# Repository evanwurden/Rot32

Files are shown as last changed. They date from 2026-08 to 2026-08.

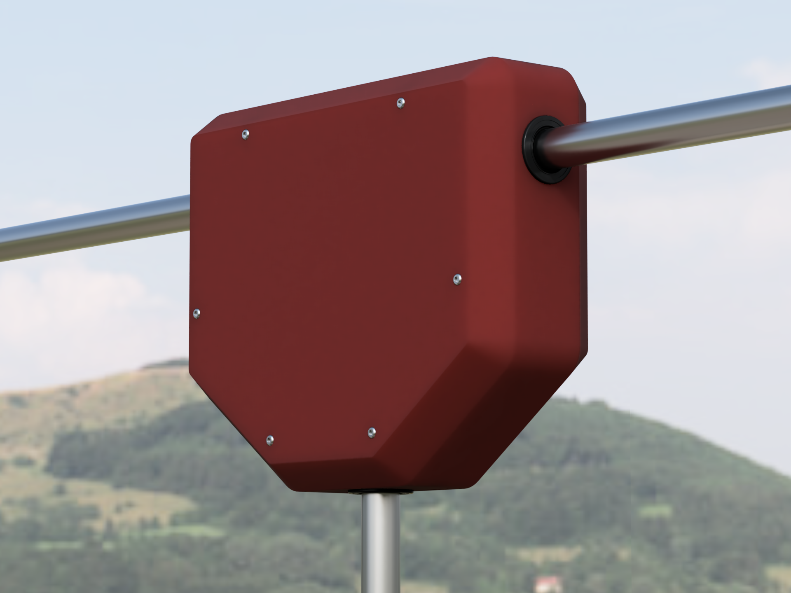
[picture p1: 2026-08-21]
3D Models/Images/AssembledView.png

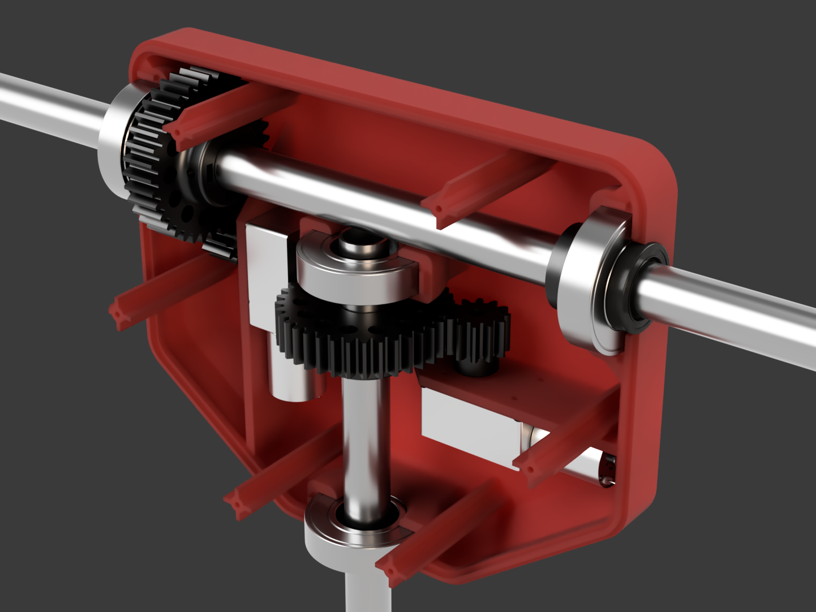
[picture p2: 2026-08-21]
3D Models/Images/TopRightView.png

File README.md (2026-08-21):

# Rot32

Rot32 is an extremely low-cost (<150USD) ESP32-based antenna rotator which is suitable for amateur radio operators or hobbyists. It utilizes commonly available hardware and is easy to assemble, wire, and program.

# Features
- 3D printable enclosure and gearing. Enclosure fits within 256x256mm bed 
- LSM303 Accelerometer/Magnetometer automatically determines the current heading and elevation
- Worm gear motor drive locks position without power applied
- Wide antenna mast can steer multiple antennas at once while staying
- Rotctld protocol emulation over Wi-Fi allows all hamlib compatible applications to interface with the rotator
- Web interface for manual steering and changing motion and calibration parameters on the fly.

<br>

# Build

## Bill Of Materials
- 1kg Spool 3D Printing Filament (Preferably PETG, ABS/ASA)
- 4x R16-2RS Ball Bearings (2in OD, 1in ID, 1/2in Thickness)
- About 5ft 0.75in aluminum tubing
- 2x JGY-370 12V 6rpm DC Worm Gear Motor
- 6x M3 Plastite Screws
- M3/M4 Nut/Screw Assortment
- ESP32-S3 Dev Board
- L298N H-Bridge Motor Driver

## Wiring

Defaults from `config.py` for ESP32-S3

| Signal | Pin |
|---|---|
| I2C SDA | GPIO8 |
| I2C SCL | GPIO9 |
| AZ+ / AZ- (PWM) | GPIO4 / GPIO5 |
| EL+ / EL- (PWM) | GPIO6 / GPIO7 |

## Firmware Install

1. Flash MicroPython from
   [micropython.org/download](https://micropython.org/download/) for your
   module.
2. Edit `config.py`: set `WIFI_SSID`, `WIFI_PASSWORD`, and the pin numbers.
3. Copy the project files to the device, e.g. `mpremote cp *.py *.html :`.
4. Reset the board. The IP address is recorded in the log, readable at
   `http://<device-ip>/api/log` or over serial with `SERIAL_LOGGING_ENABLED`.

<br>

# Usage 
## Web UI

Browse to `http://<device-ip>/` for a simple control interface:

- **Position**: live azimuth/elevation readout, plus the current target
  while a move is in progress.
- **Manual control**: press-and-hold direction buttons plus a speed slider.
- **Go To Position**: numeric azimuth/elevation entry, plus Park and Reset.
- **Motion Tuning**: arrival window, arrival speed, slow-down distance, and
  acceleration.
- **Calibration**: declination, offsets, invert flags, axis selection,
  smoothing, and a magnetometer calibration wizard.

## First-time setup

1. Pick the **azimuth forward axis**: rotate the antenna while level and try
   each of X/Y/Z until the Azimuth readout tracks correctly. Then tilt to a
   nonzero elevation and rotate again to confirm it is still accurate.
2. Pick the **elevation axis pair**: choose whichever of XY/XZ/YZ changes as
   you tilt the sensor.
3. Run the **magnetometer calibration wizard**: click Start, sweep the sensor
   through a full 360 degrees for 30 to 60 seconds, then click Finish.
4. Set **magnetic declination** for your location, then trim the azimuth and
   elevation offsets.
5. Raise **Smoothing** if the readout is jittery. Keep it at 0% while tuning
   axes and offsets so the display reacts immediately.

If azimuth is accurate at one heading but drifts at others, that is magnetic
distortion near the sensor. Use the wizard, not the offset field, which
shifts every heading by the same amount.

## rotctld

TCP server on port `4533`, accepting short and long command forms.

| Command | Long form |
|---|---|
| `P Az El` | `\set_pos` |
| `p` | `\get_pos` |
| `M Dir Speed` | `\move` |
| `S` | `\stop` |
| `K` | `\park` |
| `R 1` | `\reset` |
| `_` | `\get_info` |
| `1` | `\dump_caps` |
| `dump_state` | |

Direction values for `M`: `2` up, `4` down, `8` left, `16` right. Locator
commands are recognised but return unsupported.

```sh
printf 'p\n'         | nc 192.168.1.50 4533
printf 'P 180 30\n'  | nc 192.168.1.50 4533
printf 'M 16 60\n'   | nc 192.168.1.50 4533
printf 'S\n'         | nc 192.168.1.50 4533
```

The extended response protocol is supported by prefixing a command with `+`:

```sh
printf '+\\get_pos\n' | nc 192.168.1.50 4533
```

# Future Improvements
- Enclosure design should be tested to failure and revised accordingly. There is room for improvement in the screw standoff design which mates the two halves.
- Better waterproofing could be achieved through gasketing material around the edges and using shaft seals or some other 3D printed rubber to prevent water ingress at the bearings.
- Spur gear design can be revised to reduce backlash. A belt-drive was tested but tensioning became complicated and required more space.
- Gear-to-pipe connections should use a circumferential clamping force rather than a set screw. Aluminum is soft and a screw pressing directly into the pipe works itself loose over time.
- Encoders can be implemented for better precision. JGY worm gear motors are available with built-in encoders.
- LSM303 motion algorithm can be improved. Magnetometer calibration is quite good for static precision but polling rate and filtering could use some work.

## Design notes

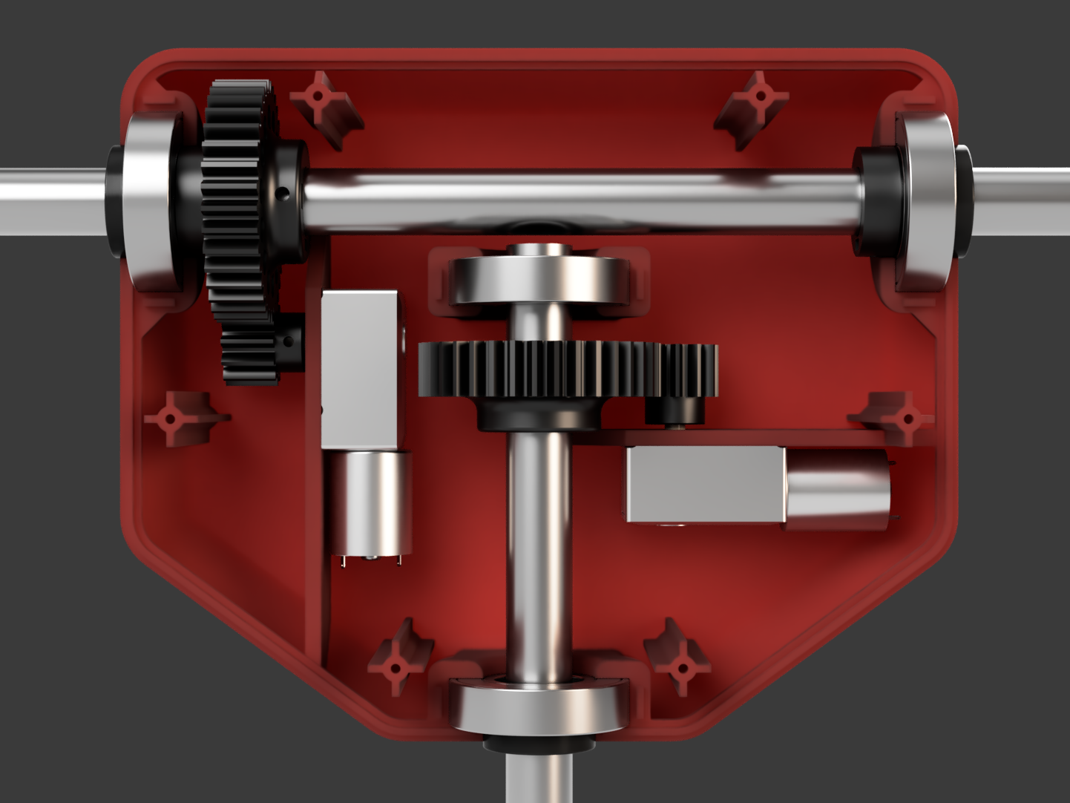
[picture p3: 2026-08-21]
3D Models/Images/FrontView.png

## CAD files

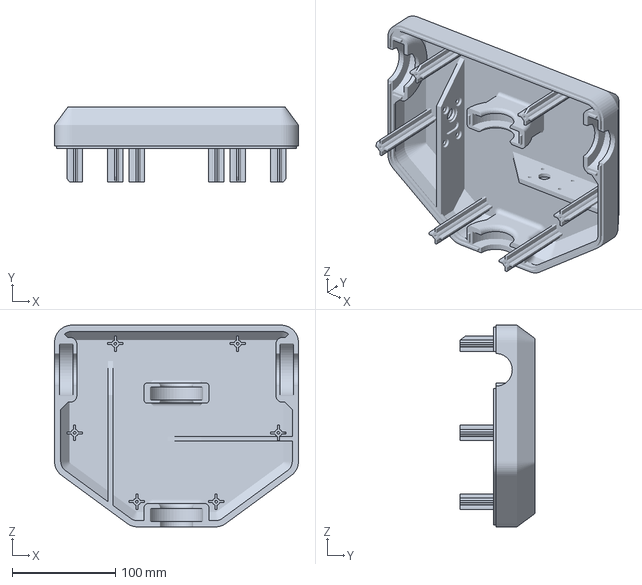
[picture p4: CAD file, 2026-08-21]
3D Models/Rotator Body Main.3mf
236.7 x 72.9 x 195.8 mm

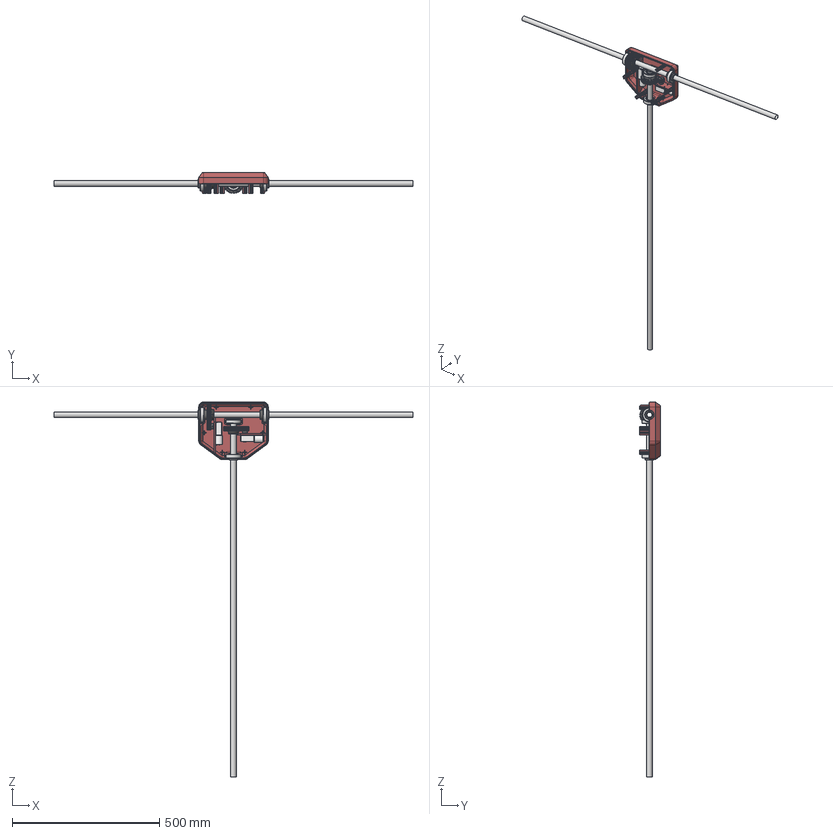
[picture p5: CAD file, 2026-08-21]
3D Models/Assembly.step
1219.2 x 72.9 x 1275.0 mm
Pipe x 2
4648K19_440C Stainless Steel Ball Bearing for Food and Beverage x 4
COVER x 2
GEAR BODY x 2
SHAFT x 2
DC MOTOR BODY x 2
DC MOTOR SHAFT x 2
M2 X 6 SS FLAT HEAD SCREW_default x 8
Spur Gear 12 teeth x 2
Spur Gear 36 teeth x 2
1199N64_Spring-Loaded Rotary Shaft Seal with Wiper Lip x 3

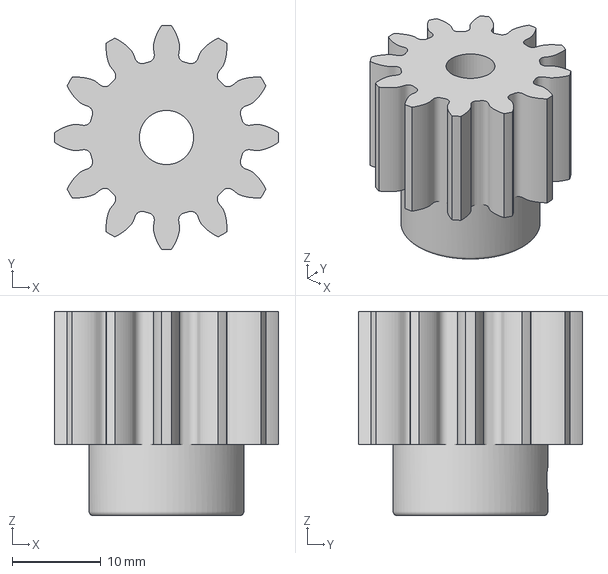
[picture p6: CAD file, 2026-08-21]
3D Models/12 Tooth Gear.3mf
25.2 x 25.2 x 23.0 mm

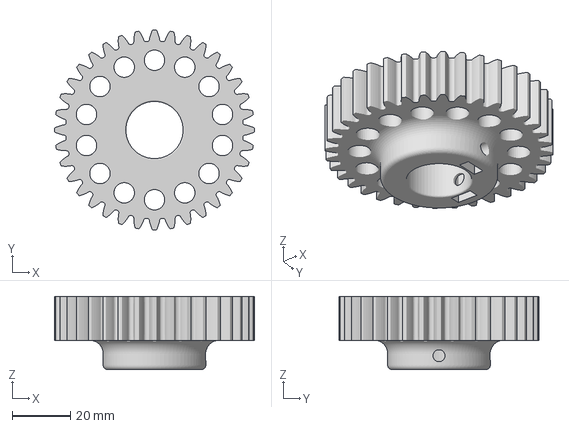
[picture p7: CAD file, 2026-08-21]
3D Models/36 Tooth Gear.3mf
68.4 x 68.4 x 25.0 mm

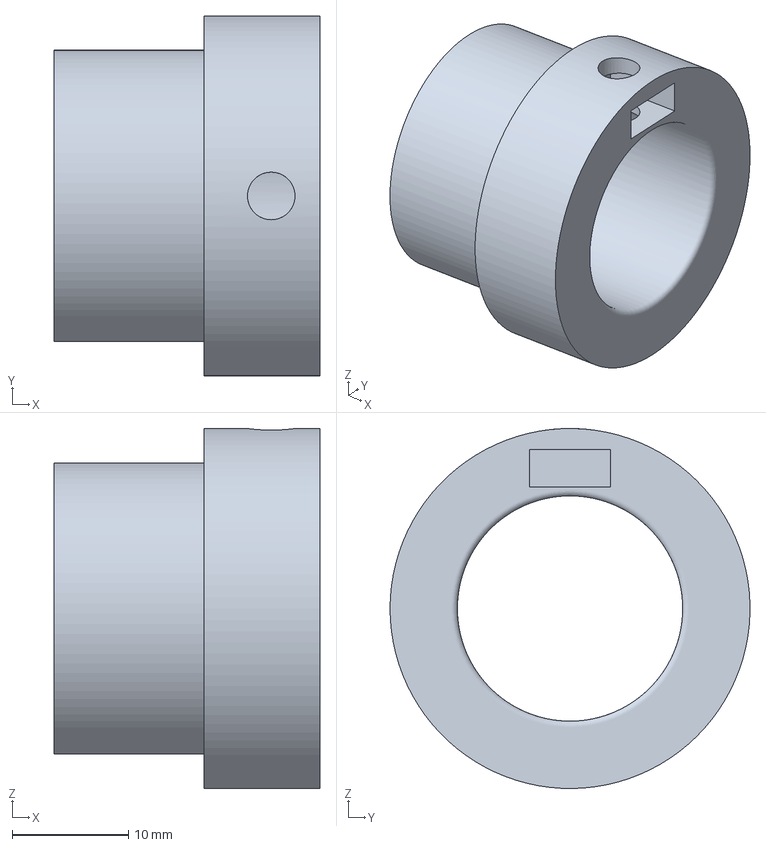
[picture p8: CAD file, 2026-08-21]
3D Models/Aluminum Tube Bearing Bushing.3mf
22.9 x 31.0 x 31.0 mm

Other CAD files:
3D Models/Rotator Body Cover.3mf

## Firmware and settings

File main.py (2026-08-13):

import time
from machine import I2C, WDT, Pin

import config
import store
from lsm303 import LSM303
from rotator_controller import RotatorController
from rotctld_server import RotctldServer
from web_server import WebServer
from wifi_manager import attempt_reconnect, connect_wifi, get_wlan, is_connected

SENSOR_RETRY_MS = 5000

# Rate limits for messages that would otherwise repeat every loop tick and
# fill up the log buffer.
ACCEPT_ERROR_LOG_MS = 5000
LOG_REPEAT_MS = 30000

# How often to retry a listening socket that is not up yet.
SERVER_REBIND_RETRY_MS = 10000

# Recent status/diagnostic messages, served at GET /api/log.
LOG_BUFFER_SIZE = 40
log_buffer = []

# Runtime copy of config.SERIAL_LOGGING_ENABLED. It turns off for good the
# first time a console write raises.
_serial_logging = config.SERIAL_LOGGING_ENABLED

_repeat_state = {}


def _default_tuning():
    """Returns config.py's motion-tuning defaults, the baseline a saved
    tuning.json overrides. Rebuilt on each call so a caller cannot mutate
    it."""
    return {
        "position_tolerance_deg": float(config.POSITION_TOLERANCE_DEG),
        "approach_speed_percent": float(config.APPROACH_SPEED_PERCENT),
        "speed_ramp_deg": float(config.SPEED_RAMP_DEG),
        "speed_accel_percent_per_sec": float(config.SPEED_ACCEL_PERCENT_PER_SEC),
    }


def _sensor_settings(saved):
    """Returns LSM303 settings from a saved calibration dict. Falls back to
    config.py for any field the dict does not have."""
    return {
        "mag_declination_deg": saved.get("mag_declination_deg", config.MAG_DECLINATION_DEG),
        "azimuth_offset_deg": saved.get("azimuth_offset_deg", config.AZIMUTH_OFFSET_DEG),
        "elevation_offset_deg": saved.get("elevation_offset_deg", config.ELEVATION_OFFSET_DEG),
        "invert_azimuth": saved.get("invert_azimuth", config.INVERT_AZIMUTH),
        "invert_elevation": saved.get("invert_elevation", config.INVERT_ELEVATION),
        "mag_offset_x": saved.get("mag_offset_x", 0.0),
        "mag_offset_y": saved.get("mag_offset_y", 0.0),
        "mag_offset_z": saved.get("mag_offset_z", 0.0),
        "mag_scale_x": saved.get("mag_scale_x", 1.0),
        "mag_scale_y": saved.get("mag_scale_y", 1.0),
        "mag_scale_z": saved.get("mag_scale_z", 1.0),
        "azimuth_forward_axis": saved.get("azimuth_forward_axis", config.AZIMUTH_FORWARD_AXIS),
        "elevation_axis_pair": saved.get("elevation_axis_pair", config.ELEVATION_AXIS_PAIR),
        "filter_strength": saved.get("filter_strength", config.FILTER_STRENGTH),
        "motion_threshold_deg": saved.get("motion_threshold_deg", config.MOTION_THRESHOLD_DEG),
        "accel_odr_hz": config.ACCEL_ODR_HZ,
        "mag_odr_hz": config.MAG_ODR_HZ,
    }


def _log(*args):
    """Appends a message to the ring buffer, and echoes it to the console if
    serial logging is on. A console write that raises turns off serial
    output for the rest of the run."""
    global _serial_logging

    msg = " ".join(str(a) for a in args)
    log_buffer.append(msg)
    if len(log_buffer) > LOG_BUFFER_SIZE:
        del log_buffer[0]
    if _serial_logging:
        try:
            print(msg)
        except Exception:
            _serial_logging = False


def _log_repeating(key, msg):
    """Logs msg, but skips an identical consecutive messages for
    LOG_REPEAT_MS."""
    now = time.ticks_ms()
    previous = _repeat_state.get(key)
    if (
        previous is not None
        and previous[0] == msg
        and time.ticks_diff(now, previous[1]) < LOG_REPEAT_MS
    ):
        return
    _repeat_state[key] = (msg, now)
    _log(msg)


class _UnavailableController:
    """Stand-in used when RotatorController fails to construct."""
    target_az = None
    target_el = None
    manual_direction = None
    manual_speed = 0
    min_elevation_deg = 0.0
    max_elevation_deg = 0.0
    last_error = None

    # Borrowed from the real controller, so /api/tuning can still show its
    # bounds.
    TUNING_LIMITS = RotatorController.TUNING_LIMITS

    def __init__(self, reason):
        self.last_error = "Motor controller unavailable: {}".format(reason)

    def get_position(self):
        return None, None

    def update(self):
        return False

    def stop(self):
        pass

    def reset(self):
        pass

    def move(self, direction, speed_percent):
        raise OSError(self.last_error)

    def set_target(self, azimuth_deg, elevation_deg):
        raise OSError(self.last_error)

    def park(self):
        raise OSError(self.last_error)

    def get_tuning(self):
        return _default_tuning()

    def set_tuning(self, **values):
        raise OSError(self.last_error)


def main():
    try:
        i2c = I2C(
            0,
            sda=Pin(config.I2C_SDA_PIN),
            scl=Pin(config.I2C_SCL_PIN),
            freq=config.I2C_FREQ_HZ,
        )
    except Exception as e:
        i2c = None
        _log("I2C bus init failed, sensor will stay unavailable:", repr(e))

    saved_cal = store.load(store.CALIBRATION_FILE)
    saved_tuning = store.load(store.TUNING_FILE)

    # Retries with an empty calibration if the saved file itself is broken
    try:
        sensor = LSM303(i2c=i2c, **_sensor_settings(saved_cal))
    except Exception as e:
        _log("Saved calibration.json invalid, falling back to config.py defaults:", repr(e))
        sensor = LSM303(i2c=i2c, **_sensor_settings({}))

    # If the sensor does not initialize, log it
    last_sensor_attempt_ms = time.ticks_ms()
    try:
        sensor.begin()
        _log("LSM303 sensor ready")
    except Exception as e:
        _log("LSM303 sensor init failed (retrying):", repr(e))

    try:
        controller = RotatorController(
            sensor=sensor,
            az_plus_pin=config.AZ_PLUS_PIN,
            az_minus_pin=config.AZ_MINUS_PIN,
            el_plus_pin=config.EL_PLUS_PIN,
            el_minus_pin=config.EL_MINUS_PIN,
            pwm_freq_hz=config.PWM_FREQUENCY_HZ,
            position_tolerance_deg=config.POSITION_TOLERANCE_DEG,
            control_update_ms=config.CONTROL_UPDATE_MS,
            min_elevation_deg=config.MIN_ELEVATION_DEG,
            max_elevation_deg=config.MAX_ELEVATION_DEG,
            park_azimuth_deg=config.PARK_AZIMUTH_DEG,
            park_elevation_deg=config.PARK_ELEVATION_DEG,
            approach_speed_percent=config.APPROACH_SPEED_PERCENT,
            speed_ramp_deg=config.SPEED_RAMP_DEG,
            speed_accel_percent_per_sec=config.SPEED_ACCEL_PERCENT_PER_SEC,
        )
    except Exception as e:
        _log("Motor controller init failed.", repr(e))
        controller = _UnavailableController(repr(e))

    if saved_tuning and not isinstance(controller, _UnavailableController):
        try:
            controller.set_tuning(**saved_tuning)
            _log("motion tuning loaded from tuning.json")
        except Exception as e:
            _log("saved tuning.json invalid, using config.py defaults:", repr(e))

    try:
        wlan = get_wlan(
            power_save_disabled=config.WIFI_POWER_SAVE_DISABLED,
            txpower_dbm=config.WIFI_TX_POWER_DBM,
        )
    except Exception as e:
        wlan = None
        _log("Wi-Fi hardware init failed:", repr(e))
    try:
        ip = connect_wifi(
            config.WIFI_SSID,
            config.WIFI_PASSWORD,
            timeout_s=config.WIFI_CONNECT_TIMEOUT_S,
            power_save_disabled=config.WIFI_POWER_SAVE_DISABLED,
            txpower_dbm=config.WIFI_TX_POWER_DBM,
        )
        _log("Wi-Fi connected, IP:", ip)
    except Exception as e:
        _log("Wi-Fi connect failed at boot (will keep retrying):", repr(e))

    server = RotctldServer(
        controller=controller,
        host=config.ROTCTLD_HOST,
        port=config.ROTCTLD_PORT,
        client_idle_ms=config.ROTCTLD_CLIENT_IDLE_MS,
        max_clients=config.MAX_CLIENTS_PER_SERVER,
    )
    try:
        server.start()
        _log("rotctld server listening on {}:{}".format(config.ROTCTLD_HOST, config.ROTCTLD_PORT))
    except Exception as e:
        _log("rotctld server failed to start:", repr(e))

    web_server = WebServer(
        controller=controller,
        sensor=sensor,
        store=store,
        default_tuning=_default_tuning(),
        wlan=wlan,
        log_buffer=log_buffer,
        host=config.WEB_HOST,
        port=config.WEB_PORT,
        client_idle_ms=config.WEB_CLIENT_IDLE_MS,
        max_clients=config.MAX_CLIENTS_PER_SERVER,
    )
    try:
        web_server.start()
        _log("web UI listening on {}:{}".format(config.WEB_HOST, config.WEB_PORT))
    except Exception as e:
        _log("web server failed to start:", repr(e))

    last_wifi_attempt_ms = time.ticks_ms()
    wifi_was_connected = is_connected(wlan)
    wifi_failures = 0
    last_accept_log_ms = time.ticks_ms()
    last_bind_retry_ms = time.ticks_ms()
    bind_failure_logged = set()

    def _rebind(srv, name):
        """Reopens a server's listening socket after Wi-Fi comes back."""
        try:
            srv.restart()
            _log(name, "rebound after Wi-Fi reconnect")
        except Exception as e:
            _log(name, "failed to rebind after Wi-Fi reconnect:", repr(e))

    wdt = None
    if config.WDT_ENABLED:
        try:
            wdt = WDT(timeout=config.WDT_TIMEOUT_MS)
            _log("watchdog armed ({} ms)".format(config.WDT_TIMEOUT_MS))
        except Exception as e:
            _log("watchdog unavailable (continuing without it):", repr(e))

    try:
        while True:
            if wdt is not None:
                wdt.feed()

            now = time.ticks_ms()

            if wlan is not None and is_connected(wlan):
                if not wifi_was_connected:
                    _log("Wi-Fi connected, IP:", wlan.ifconfig()[0])
                    # A socket bound before the interface went down does not
                    # reliably keep accepting once the interface is rebuilt.
                    _rebind(server, "rotctld server")
                    _rebind(web_server, "web server")
                wifi_was_connected = True
                wifi_failures = 0
            else:
                if wifi_was_connected:
                    _log("Wi-Fi disconnected")
                wifi_was_connected = False
                if wlan is not None and time.ticks_diff(now, last_wifi_attempt_ms) >= config.WIFI_RECONNECT_MS:
                    last_wifi_attempt_ms = now
                    wifi_failures = attempt_reconnect(
                        wlan,
                        config.WIFI_SSID,
                        config.WIFI_PASSWORD,
                        consecutive_failures=wifi_failures,
                        hard_reset_after=config.WIFI_HARD_RESET_AFTER_ATTEMPTS,
                        power_save_disabled=config.WIFI_POWER_SAVE_DISABLED,
                        txpower_dbm=config.WIFI_TX_POWER_DBM,
                    )
                    _log("Wi-Fi reconnect attempt", wifi_failures)

            if time.ticks_diff(now, last_accept_log_ms) >= ACCEPT_ERROR_LOG_MS:
                last_accept_log_ms = now
                for srv, name in ((server, "rotctld"), (web_server, "web")):
                    if srv.last_accept_error is not None:
                        _log(
                            name,
                            "accept failed (socket pool exhausted?):",
                            srv.last_accept_error,
                        )
                        srv.last_accept_error = None

            # Retries any listening socket that is not up
            if time.ticks_diff(now, last_bind_retry_ms) >= SERVER_REBIND_RETRY_MS:
                last_bind_retry_ms = now
                for key, srv, name in (
                    ("rotctld", server, "rotctld server"),
                    ("web", web_server, "web server"),
                ):
                    if srv.server is not None:
                        continue
                    try:
                        srv.start()
                        bind_failure_logged.discard(key)
                        _log(name, "listening again")
                    except Exception as e:
                        if key not in bind_failure_logged:
                            bind_failure_logged.add(key)
                            _log(name, "not listening, will keep retrying:", repr(e))

            if not sensor.ready:
                if time.ticks_diff(now, last_sensor_attempt_ms) >= SENSOR_RETRY_MS:
                    last_sensor_attempt_ms = now
                    try:
                        sensor.begin()
                        _log("LSM303 sensor ready")
                    except Exception as e:
                        _log_repeating(
                            "sensor", "LSM303 sensor init retry failed: " + repr(e)
                        )

            try:
                if controller.update():
                    controller.last_error = None
            except Exception as e:
                controller.last_error = "{}: {}".format(type(e).__name__, e)
                _log_repeating(
                    "control", "controller update error: " + controller.last_error
                )

            try:
                server.poll_once()
            except Exception as e:
                _log("server poll error:", repr(e))
            try:
                web_server.poll_once()
            except Exception as e:
                _log("web server poll error:", repr(e))

            # Keep this below CONTROL_UPDATE_MS
            time.sleep_ms(10)
    finally:
        controller.stop()
        server.close()
        web_server.close()


if __name__ == "__main__":
    main()

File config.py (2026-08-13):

"""Rot32 configuration"""

# Wi-Fi settings
WIFI_SSID = "YOUR_SSID_HERE"
WIFI_PASSWORD = "YOUR_PASS_HERE"

# WIFI_CONNECT_TIMEOUT_S: how long the boot connect waits before it gives
# up. This does not stop startup.
WIFI_CONNECT_TIMEOUT_S = 20
# WIFI_RECONNECT_MS: how often it retries the connection while offline
WIFI_RECONNECT_MS = 10_000

WIFI_HARD_RESET_AFTER_ATTEMPTS = 5
WIFI_POWER_SAVE_DISABLED = True

# Transmit power cap in dBm. None leaves it uncapped
WIFI_TX_POWER_DBM = None

# Hardware watchdog
WDT_ENABLED = True
WDT_TIMEOUT_MS = 30000

# Logs to the serial console. Keep this off without a USB connection
SERIAL_LOGGING_ENABLED = False

# rotctld server settings
ROTCTLD_HOST = "0.0.0.0"
ROTCTLD_PORT = 4533

# Web control/calibration UI settings
WEB_HOST = "0.0.0.0"
WEB_PORT = 80

# Closes an idle client after no traffic for this long
WEB_CLIENT_IDLE_MS = 15_000
ROTCTLD_CLIENT_IDLE_MS = 300_000

MAX_CLIENTS_PER_SERVER = 4

# I2C pins for the LSM303 sensor. GPIO8 and GPIO9 are safe on ESP32-S3
I2C_SDA_PIN = 8
I2C_SCL_PIN = 9
I2C_FREQ_HZ = 400_000

# LSM303 output data rates.
# ACCEL_ODR_HZ (1/10/25/50/100/200/400)
ACCEL_ODR_HZ = 100
# MAG_ODR_HZ (15/30/75/220)
# Keep this above 1000/CONTROL_UPDATE_MS. Otherwise the control loop reads
# stale values.
MAG_ODR_HZ = 75

# Motor driver. GPIO4 to GPIO7 are safe on ESP32-S3
AZ_PLUS_PIN = 4
AZ_MINUS_PIN = 5
EL_PLUS_PIN = 6
EL_MINUS_PIN = 7
PWM_FREQUENCY_HZ = 500

# Control loop period, roughly 50 Hz
CONTROL_UPDATE_MS = 20

POSITION_TOLERANCE_DEG = 1.5
MAX_ELEVATION_DEG = 90.0
MIN_ELEVATION_DEG = -10.0

# Speed ramping. APPROACH_SPEED_PERCENT is the speed the rotator arrives at,
# SPEED_RAMP_DEG is how far out the taper down to it begins, and
# SPEED_ACCEL_PERCENT_PER_SEC caps how fast commanded speed may change.
APPROACH_SPEED_PERCENT = 15.0
SPEED_RAMP_DEG = 15.0
SPEED_ACCEL_PERCENT_PER_SEC = 200.0

# Optional sensor/orientation calibration
MAG_DECLINATION_DEG = 0.0
AZIMUTH_OFFSET_DEG = 0.0
ELEVATION_OFFSET_DEG = 0.0
INVERT_AZIMUTH = False
INVERT_ELEVATION = False

# AZIMUTH_FORWARD_AXIS: axis that lies parallel to the antenna. 
AZIMUTH_FORWARD_AXIS = "X"

# ELEVATION_AXIS_PAIR: axis pair ("XY", "XZ" or "YZ") that
# elevation reads from. Pick the pair that changes as you tilt the sensor.
ELEVATION_AXIS_PAIR = "XZ"

# Exponential-moving-average smoothing on the azimuth and elevation output
FILTER_STRENGTH = 0.95

# Deviation above which smoothing turns off and a reading is treated as a
# real move, not wind or noise
MOTION_THRESHOLD_DEG = 3.0

# Park position
PARK_AZIMUTH_DEG = 0.0
PARK_ELEVATION_DEG = 0.0

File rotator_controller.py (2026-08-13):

import time
from machine import PWM, Pin


class RotatorController:
    """Closed-loop azimuth and elevation control using four PWM outputs that
    drive an H-bridge."""

    DIR_UP = 2
    DIR_DOWN = 4
    DIR_LEFT = 8
    DIR_RIGHT = 16

    # Largest gap, as a multiple of control_update_ms, that one cycle may
    # use for its acceleration step
    MAX_RAMP_INTERVAL_FACTOR = 4

    # Motion parameters editable via the web UI or /api/tuning.
    # Bounds apply on every write.
    TUNING_LIMITS = {
        "position_tolerance_deg": (0.1, 30.0),
        "approach_speed_percent": (1.0, 100.0),
        "speed_ramp_deg": (1.0, 180.0),
        "speed_accel_percent_per_sec": (1.0, 10000.0),
    }

    def __init__(
        self,
        sensor,
        az_plus_pin,
        az_minus_pin,
        el_plus_pin,
        el_minus_pin,
        pwm_freq_hz,
        position_tolerance_deg,
        control_update_ms,
        min_elevation_deg,
        max_elevation_deg,
        park_azimuth_deg,
        park_elevation_deg,
        approach_speed_percent=15.0,
        speed_ramp_deg=15.0,
        speed_accel_percent_per_sec=200.0,
    ):
        self.sensor = sensor

        self.az_plus_pwm = PWM(Pin(az_plus_pin))
        self.az_minus_pwm = PWM(Pin(az_minus_pin))
        self.el_plus_pwm = PWM(Pin(el_plus_pin))
        self.el_minus_pwm = PWM(Pin(el_minus_pin))
        for pwm in (self.az_plus_pwm, self.az_minus_pwm, self.el_plus_pwm, self.el_minus_pwm):
            pwm.freq(pwm_freq_hz)

        self.position_tolerance_deg = position_tolerance_deg
        self.control_update_ms = control_update_ms
        self.min_elevation_deg = min_elevation_deg
        self.max_elevation_deg = max_elevation_deg

        self.park_azimuth_deg = park_azimuth_deg
        self.park_elevation_deg = self._clamp_elevation(park_elevation_deg)

        self.approach_speed_percent = approach_speed_percent
        self.speed_ramp_deg = speed_ramp_deg
        self.speed_accel_percent_per_sec = speed_accel_percent_per_sec

        # Speed change allowed this cycle
        self._max_speed_change = speed_accel_percent_per_sec * (
            control_update_ms / 1000.0
        )

        self.current_az = 0.0
        self.current_el = 0.0

        self.target_az = None
        self.target_el = None

        self.manual_direction = None
        self.manual_speed = 0

        self._have_position = False

        self.last_error = None

        self._az_speed = 0.0
        self._el_speed = 0.0

        self._last_control_ms = time.ticks_ms()

        self.stop()

    @staticmethod
    def _wrap_360(value):
        while value < 0.0:
            value += 360.0
        while value >= 360.0:
            value -= 360.0
        return value

    @staticmethod
    def _shortest_az_error(target, current):
        error = (target - current + 540.0) % 360.0 - 180.0
        return error

    def _clamp_elevation(self, elevation):
        if elevation < self.min_elevation_deg:
            return self.min_elevation_deg
        if elevation > self.max_elevation_deg:
            return self.max_elevation_deg
        return elevation

    @staticmethod
    def _speed_to_duty_u16(speed_percent):
        speed_percent = max(0, min(100, int(speed_percent)))
        return int((speed_percent * 65535) / 100)

    def _set_axis_pwm(self, plus_pwm, minus_pwm, signed_speed_percent):
        duty = self._speed_to_duty_u16(abs(signed_speed_percent))
        if signed_speed_percent > 0:
            plus_pwm.duty_u16(duty)
            minus_pwm.duty_u16(0)
        elif signed_speed_percent < 0:
            plus_pwm.duty_u16(0)
            minus_pwm.duty_u16(duty)
        else:
            plus_pwm.duty_u16(0)
            minus_pwm.duty_u16(0)

    @staticmethod
    def _stop_axis_pwm(plus_pwm, minus_pwm):
        plus_pwm.duty_u16(0)
        minus_pwm.duty_u16(0)

    def _refresh_position(self):
        self.current_az, self.current_el = self.sensor.read_orientation()
        self._have_position = True

    def get_position(self):
        """Returns the latest position from the control loop's last
        sample."""
        if not self._have_position:
            self._refresh_position()
        return self.current_az, self.current_el

    def set_target(self, azimuth_deg, elevation_deg):
        self.target_az = self._wrap_360(float(azimuth_deg))
        self.target_el = self._clamp_elevation(float(elevation_deg))
        self.manual_direction = None
        self.manual_speed = 0

    def move(self, direction, speed_percent):
        self.manual_direction = int(direction)
        self.manual_speed = max(0, min(100, int(speed_percent)))
        self.target_az = None
        self.target_el = None

    def stop(self):
        self.manual_direction = None
        self.manual_speed = 0
        self.target_az = None
        self.target_el = None
        self._az_speed = 0.0
        self._el_speed = 0.0
        self._stop_axis_pwm(self.az_plus_pwm, self.az_minus_pwm)
        self._stop_axis_pwm(self.el_plus_pwm, self.el_minus_pwm)

    def park(self):
        self.set_target(self.park_azimuth_deg, self.park_elevation_deg)

    def reset(self):
        self.stop()

    def get_tuning(self):
        return {name: getattr(self, name) for name in self.TUNING_LIMITS}

    @classmethod
    def _validate_tuning(cls, values):
        if values["speed_ramp_deg"] <= values["position_tolerance_deg"]:
            raise ValueError(
                "Slow-down distance ({:.2f}deg) must be greater than the arrival"
                " window ({:.2f}deg), or there is no room to slow down in".format(
                    values["speed_ramp_deg"], values["position_tolerance_deg"]
                )
            )

    def set_tuning(self, **values):
        """Validates and applies motion tuning"""
        candidate = self.get_tuning()

        for name, value in values.items():
            if value is None:
                continue
            if name not in self.TUNING_LIMITS:
                raise ValueError("Unknown tuning parameter: {}".format(name))
            try:
                value = float(value)
            except (TypeError, ValueError):
                raise ValueError("{} must be a number".format(name))
            low, high = self.TUNING_LIMITS[name]
            if value < low or value > high:
                raise ValueError(
                    "{} must be between {} and {} (got {})".format(name, low, high, value)
                )
            candidate[name] = value

        self._validate_tuning(candidate)

        for name, value in candidate.items():
            setattr(self, name, value)
        return self.get_tuning()
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
